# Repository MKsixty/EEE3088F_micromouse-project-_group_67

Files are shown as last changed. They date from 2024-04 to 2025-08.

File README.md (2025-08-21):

# EEE3088F_micromouse-project-_group_67

Overview

This repository contains the design files, documentation, and testing results for the sensor subsystem of a Micromouse robot, developed as part of the EEE3088F course at the University of Cape Town. The sensor board is designed as a custom PCB inspired by the UCLA Micromouse project but tailored through specific design decisions to meet project requirements and ensure optimal performance. Its primary role is to provide reliable wall detection on the front, left, and right sides of the Micromouse to enable autonomous maze navigation.

Design Summary

Emitters & Detectors: Uses IR333C infrared LEDs and TEFT4300 phototransistors, chosen for their closely matched wavelength (≈940 nm) for fast response and accurate detection.

Emitter Circuit: Powered by the 3.7 V LiPo battery, with 47 Ω current-limiting resistors ensuring ~70 mA drive for strong radiant intensity. 4.7 μF bypass capacitors filter noise on the LED supply.

Switching: Implemented with MMBF170 N-channel MOSFETs driven by STM32L476 PWM GPIOs. Gate resistors (100 Ω) and pulldowns (47 kΩ) ensure safe and stable operation.

Receiver Circuit: Uses a voltage divider (470 Ω & 1.5 kΩ) to keep outputs <3.3 V for STM32 ADC compatibility. A unity-gain buffer with LM324 op-amp protects ADC inputs from noise and spikes.

Form Factor: PCB dimensions ≤70 mm × 30 mm, cost-effective, and compatible with standard JLCPCB manufacturing limits.

Failure Management: Includes test points, through-hole components for easy rework, and jumper options to adjust resistor networks if needed.

Features

Accurate wall detection at up to 15 cm.

PWM-controlled IR switching for power efficiency.

Designed for direct integration with the STM32L476 processor board via a 14×2 pin header.

Supports three independent sensor channels (front, left, right).

Repository Contents

PCB design files and schematics.

Component datasheets (IR333C, TEFT4300, LM324, MOSFETs).

Integration code for STM32L476 (sensor readout and PWM control).

Project report, test logs, and acceptance test procedures.

Testing

The board underwent short-circuit checks, current consumption tests, PWM switching validation, and functional wall-detection tests. Issues such as LED orientation errors and interference between sensors were identified and mitigated using jumper reconfiguration and potential PWM timing adjustments in firmware.

Future Improvements

Implement time-multiplexed PWM driving to reduce crosstalk between sensors.

Optimize current draw to meet <100 mA power efficiency target.

Explore improved ADC filtering for cleaner sensor output.

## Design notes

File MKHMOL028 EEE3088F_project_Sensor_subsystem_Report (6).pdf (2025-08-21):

# Interim Design Report

Micromouse sensor Subsystem


Prepared by:
Molise Mokhakala

Prepared for:
EEE3088F
Department of Electrical Engineering University of Cape Town

May 17, 2024

# Declaration

1. I know that plagiarism is wrong. Plagiarism is to use another’s work and pretend that it is one’s own.
2. I have used the IEEE convention for citation and referencing. Each contribution to, and quotation in, this report from the work(s) of other people has been attributed, and has been cited and

referenced.

3. This report is my own work.
4. I have not allowed, and will not allow, anyone to copy my work with the intention of passing it off as their own work or part thereof.

May 17, 2024

Name Surname | Date

ii

# Contents

1 Introduction | 1
2 Requirements Analysis | 2
3 Subsystem Design | 4
4 Acceptance Testing | 9

iii

# Chapter 1

# Introduction

## 1.1 Problem Description

The aim of this project is to design and manufacture a sensor module for a micromouse. A micromouse is a small robot that can autonomously move through a maze to get to the centre.The sensor subsystem plays a crucial role of being the micromouse’s eyes in order to accomplish the aforementioned. As

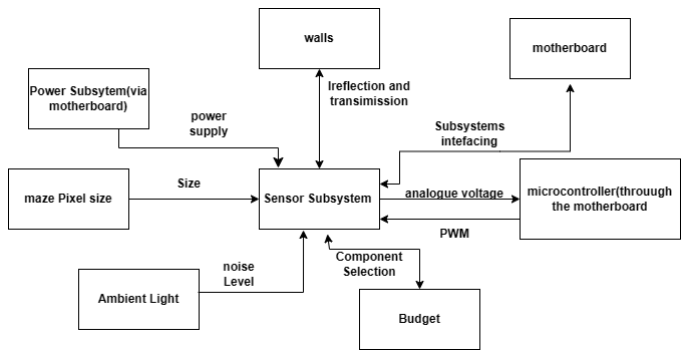
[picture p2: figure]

Figure 1.1: Context diagram for the sensor subsystem in the whole project

illustrated in the above figure, the sensor subsystem primarily detects obstacles in the environment of the micro-mouse specifically walls in front and on the side of the micromouse using transmission and reflection. Subsequently this allows the mouse to identify and avoid collisions with walls, adjusting its path accordingly to successfully reach the center. The microprocessor using its ADC examines analogue voltage outputs from the sensor to determine the presence of the wall.

## 1.2 Scope and Limitations

The project’s focus is to design PCB boards for the sensor submodule and write code necessary for integration of the PCB with the microprocessor boards. The PCB must primarily offer effective and accurate wall detection in front and on the micro-mouse’s right and left sides. The subsystem is to be designed to utilise switching techniques that enabling to have efficient battery use. Furthermore, testing procedures concentrate on the functionality of the sensor subsystem within the given requirements. However, this subsystem does not include the design or manufacture of the processor board and power subsystem . Testing is not conducted of the power subsystems and other subsystems. The manufacture of the two PCBs is limited to a maximum of $30. Additional restriction include no prototyping due to

limited time before demonstration.

## 1.3 GitHub Link

repo link (contains datasheets and project versions references in the document) (https://github.com/MKsixty/EEE3088F_micromouse-project-_group_67)

# Chapter 2

# Requirements Analysis

## 2.1 Requirements

The requirements for a micromouse power module are described in Table 2.1.

Table 2.1: User and functional requirements of the Sensor subsystem.

Requirement ID | Description
UR01 | It should have a switching mechanism
FR01 | It must detect walls in front and on the side of the micromouse
UR02 | It must be of the appropriate geometry for the maze pixels
UR03 | It must be cost-effective. Two PCBs cost at most $30
UR04 | Its pin headers must connect to the motherboard at the right configuration for STM32L476
UR05 | It should use only components available on JLCPCB excluding the pin headers
FR02 | the sensor output must be analogue
FR03 | It should reduce ambient light effects
FR04 | It should be power efficient and not drain the battery before completing the maze.
FR05 | should be capable of using LiPo 800mAh 3.7V power supply
FR06 | have written code that allows sensing board to detect walls in front, to the left and to the right of the micromouse.

## 2.2 Specifications

The specifications, refined from the requirements in Table 2.1, for the micromouse sensor module are described in Table 2.2.

Table 2.2: Specifications of the sensing subsystem derived from the requirements in Table 2.1.

Specification ID | Requirements ID | Description
SP01 | UR01 | IR LED switches on when microcontroller GPIO pins’PWM reaches 3.3V and is off below 2.5V
SP02 | FR01 | should have 3 sensors per PCB (one at the front and two on the sides) with detection range of 15cm
SP03 | FR01 | use 900-950nm Infrared LED and detector
SP04 | FR02 | the sensor output is analogue voltage in the range 0V to 2.8V
SP05 | FR03 | Photo-detector has daylight blocking filter with bandwidth matched with 900-950nm IR emitters
SP06 | FR04 | only 100mA when all 3 sensors are operational
SP07 | FR05 | the IR emitter and detector should work on the LiPo 800mAh 3.7V
SP08 | UR02 | must have maximum width of 30mm and length of 70mm
SP09 | UR03 | have a maximum of 4 low cost JLCPCB extended components
| UR05 | and the rest should be basic
SP10 | UR04 | 14x2 odd even standard pinheaders should be on sensor board
| | and matches the processor board connections thus the testing booad
SP11 | FR06 | Code must be compatible with the 2nd year STM32F0 devkit and toggle PB7 for left, PB6 For front and PB5 for right

## 2.3 Testing Procedures

A summary of the testing procedures detailed in chapter 4 is given in Table 2.3.

2.4. Traceability Analysis

Table 2.3: acceptance tests summary

Acceptance Test ID | Description
AT01 | short circuit test
AT02 | check if N mosfet low side switching works
AT03 | check if IR LEDs work
AT04 | check current consumption
AT05 | check if PWM switching mechanism works
AT06 | check if receiver circuit works
AT07 | check if walls can be detected
AT08 | check code used for integration works
AT09 | check if 14x2 pin headers can fit into the slots on processor board
AT09 | confirm board size

## 2.4 Traceability Analysis

The show how the requirements, specifications and testing procedures all link, Table 2.4 is provided.

Table 2.4: Requirements Traceability Matrix

# | Requirements | Specifications | Acceptance Test

1 2 3 4 5 6 7 9 10 | UR01 FR01 FR02 FR03 FR04 FR05 UR02 FR06 UR04 | SP01 SP02, SP03 SP04 SP05 SP06 SP07 SP08 SP11 SP10 | AT05,AT02 AT04,AT07,AT08 AT07 AT06 AT04 AT01 AT10 AT07 AT09

### 2.4.1 Traceability Analysis 1

UR01 is this from which SP01, use of PWM as swicthing means, can be derived. This is because the provided microcontroller offer PWM. To test this AT05 and AT02 are suggested because these test whether the mosfet used does switch or not.

From FR01, SP02 and SP03 can be derived because for the sensor subsystem to be functional in the task of sensing the walls on the side and front, all three sensor must use IR transmission and reflection to detect obstacle. These can be tested through AT07,AT08 and AT04 which tests if the emitter and transmitter are functional .This is because this tests require all three of the sensors to be operational

From FR02 , sP02 is derived because inorder for the sensor to have output that is analogue and can be used by the microcontroller ADC it is limited to 0-2.8V. Subsequently this means test AT07 confirms whether the voltage registered when an obstacle is present indeed falls with the 0-2.8V limit.

# Chapter 3

# Subsystem Design

## 3.1 Design Decisions

The detection of the wall, requires a wave that can be transmitted by the sensor subsystem and reflected by the wall back to the subsystem. Although there are various waves that can be used such as sound, this design will use Infrared as it is faster than sound moving at the speed of light. Thus this would give the micromouse a fast response. The 3.1 gives comparisons made between the most feasible emitters for the sensor subsystem.

Table 3.1: IR emitter component selection

| forward current(typ) | forward current | Power Dissipation | Spectral range Sensitivity | Peak Wavelength | half angle(Deg) | Cost
TSAL6100 | 1.35V | 100mA | 160mW | 910-970nm | 940nm | 10 | $0.2147
IR333C | 1.2V | 20mA | 150mW | 895-995nm | 940nm | 20 | $0.0339
SFH4556 | 1.5V | 100mA | 150mW | 820-860nm | 840nm | 20 | $0.6120

Table 3.2: IR emitter component selection pros against cons comparison

| TSAL6100 | SFH4556 | IR333C
pros | least expensive, meeting the UR03 requirement | 20 degrees half angle making it large enough for side wall detection(FR01) especially if the emitter needs to be placed at an angle on the PCB. | low current requirement for peak wavelength of 940nm, meeting SP05 Half angle same as SFH4556 making it also suitable for FR01 lowest voltage drop at peak walength current of 1.2V
cons | small wavelength spectral range make it less suitable for spectral range less than 900nm which could be generated if there slight changes current values | most expensive thus less likely if UR03 is to be met high current requirement of 100mA for peak wavelength the highest voltage drop of 1.5 V | lower maximum power dissipation of 150 compared to the other two.

IR333C is selected given its advantages over the other components and although it has one the lower maximum power dissipation values,given it will not be driven to close to the max dissipation value it should be fine.

The use of pulse width modulation(PWM) requires the use of components that can switch on and off

depending on whether the supply is high or low . Transistor are useful in this regard. Subsequently for low side switching which is easy to implement, a comparison between the NPN BJT ZTX652 and N channel mosfet MMBF170 on their effectiveness in this configuration is made .

MMBF170 provides faster and more stable switching at a lower cost than ZTX652. Although more difficult to hand solder than ZTX652, it can still be hand soldered meaning this does not negate the

3.1. Design Decisions

Table 3.3: SWitching component selection pros against cons comparison

| MMBF170(N-channel Mosfet) | ZTX652(NPN BJT)
pro | Idmax =0.5A meaning it can carry the 20mA required by IR333C low voltage requirement of 0.13V at 250mA which means it can dissipate less power It is an SMD thus is small can save space on the PCB subsequently helping in achieving UR02. faster switching time as shown in table for both the switching on and off thus making it more suitaable for SP06 and SP05 As a mosfet it has a high current gain making more stable for changing drain currents and more stable than the ZTX652 | is THT thus is easier to solder by hand if revision are needed Typically needs atleast +0.9V at the base thus can work at the 3.3V of the microcontroller. Thus making it more suitable for achieving SP06 and SP05.
cons | It is small making it hard to solder by hand if revisions are needed Needs more voltage to be active which is greater or equal to Vgs threshold of 1.6V | since it is a BJT, it is slightly more affected by temperatures making it less stable in switching costs more thus making it difficult to achieve UR03

MMBF170 use in the circuit. Thus MMBF170 was selected for this design.

Given the selection of the IR333C, the following receivers are selected as feasible components as they are sensitive to IR333C’s peak wavelength of 940nm.

Table 3.4: IR receiver component selection

| forward voltage | daylight blocking | wavelength of max sensitivity | spectral range | half angle | unit cost
BPV10NF | VR=0.85V at IR=50mA | present 850-950nm | 940 | 780-1050 | 20 | $0.4035 (extended)
TEFT4300 | VCE sat = 0.3 | Present 900-950nm | 925nm | 875-1000nm | 30 | $0.2147 (extended)

Table 3.5: IR receiver component pros and cons

| BPV10NF | TEFT4300
Pro | has a larger daylight-blocking filtering in the range 780-1050nm hence can filter more of the ambient light compared to TEFT4300.Thus making it very useful in achieving SP03 has a peak detection wavelength of 940nm which exactly matches IR333C’s thus can operate at optimum detection level | has a daylight blocking filter range 875-1000nm so can still be used to meet SP03. has a larger half angle of 30 degrees thus can be useful for detection at angles. Thus becomes very useful for FR01. costs less at $0.2147
cons | more expensive at $0.4035 | has a lower peak wavelength detection of 925nm compared to the transmitted one of IR333C of 940nm

TEFT4300 is selected over BPV10NF because it costs less subsequently is effective in achieving UR03 and SP10. Even though it has a lower peak wavelength of 925nm while BPV10NF has a peak wavelength of 940nm which is exactly 940nm, the larger half angle is another reason it was choosen. This is because IR333C gives off a range of wavelengths 895-995nm thus 925nm is also radiated. Subsequently this means the wavelength disadvantage is overlooked and TEFT4300 was selected.

3.1. Design Decisions

### 3.1.1 Final Design

The following design are inspired by ucla micromouse design (https://projects.ieeebruins.com/micromouse/) however meticulous design decisions were made to the project’s requirements and to ensure optimal performance and functionality. The IR333C and TEFT4300 are selected for their matching wavelength ranges, which enables fast response time. Given that as microcontroller STM32L476’s GPIOs give out low currents, the IR333C emitter circuitand The receiver circuits are also supplied by the 3.7 V battery from the power subsystem. 47 ohm resistor is choosen to limit the current through the IR333C whilst ensuring it has current of 70mA which results in IR333C large radiant intensity. The 4.7 uF bypass capacitors across the LEDs ensures a clear signals when supplied by DC.

The 47k resistor connected to ground is placed at the gate of N channel mosfet to ensure the gate is zero when there is no voltage supplied. The gate of the MMBF170s is connected to the GPIO PE of the microcontroller for PWM since for the N channel mosfets current is not a requirement to switch on. MMBF170’s gate to source threshold voltage is 1.6V thus 3.3V of the pins will switch the mosfets on. 100 ohm resistors at each of the MMBF170’s gate is used for current limiting.
The unity voltage buffer is used in the circuit to protect the ADC from sudden spikes in voltage as a result of noise. The IC LM324 is then used because it reduces the space used thus achieving UR03. Voltage divider in the receiver circuit consisting of 470 and 1.5 k ohm resistors to ensure that the output is less than 3.3V of the inbuilt ADC of STM32L476.
A detail schematic with the above decisions is shown below.

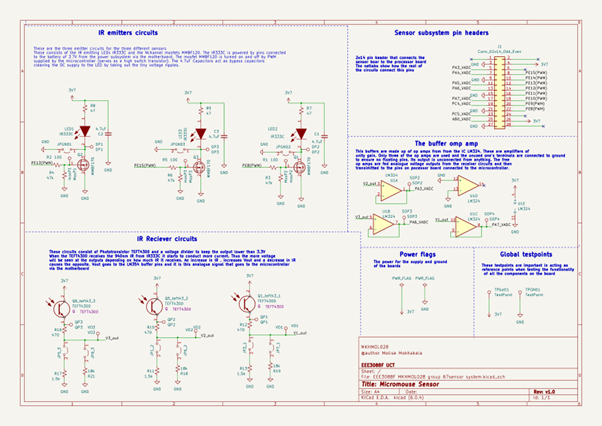
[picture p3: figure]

Figure 3.1: Schematic

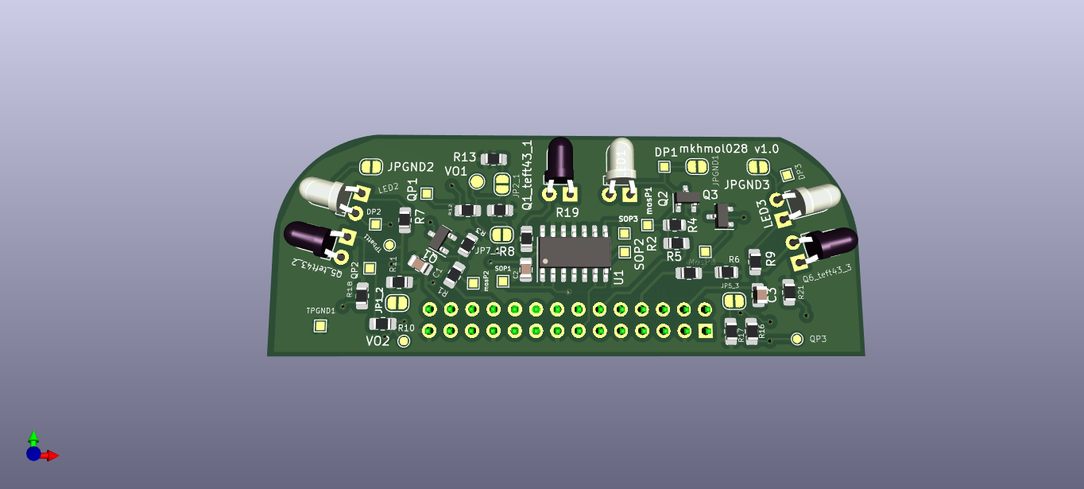
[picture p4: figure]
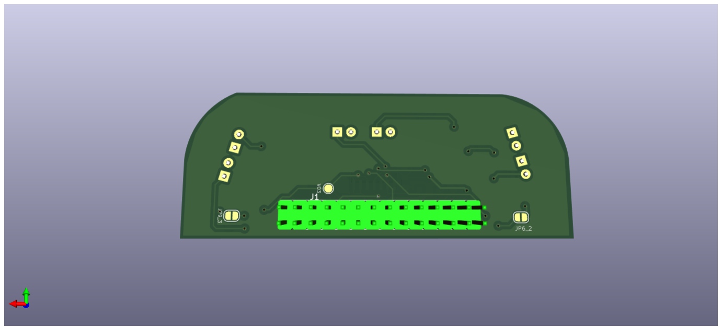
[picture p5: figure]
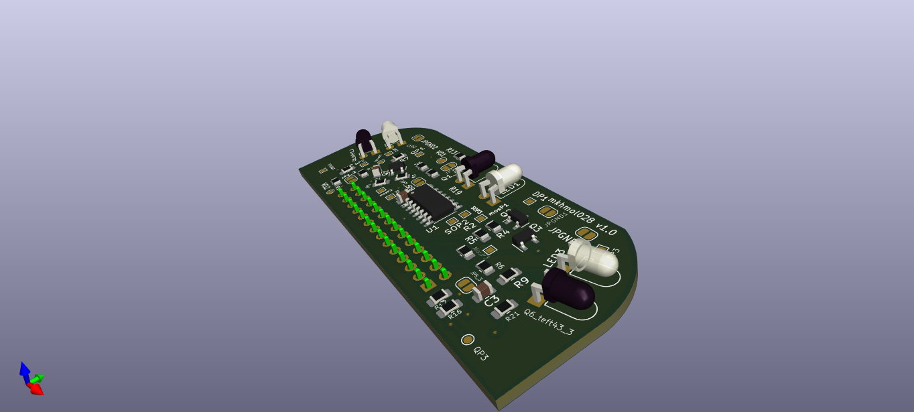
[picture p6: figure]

(a) Front PCB | (b) Back PCB | (c) 3D PCB

Figure 3.2: PCB

3.2. Failure Management

## 3.2 Failure Management

Table 3.6: failure Precautions used in the PCB

Name | Description
Test Points | Varies test points are placed all over the board across vital components to dectect specific component failures. The testpoints are named according the components they are to be used in testing for. Example DP3 is the test point for the IR333C giving out V3out in the Schematic The voltage across the components can be determined using the global tespoints TPbatt(battery testpoint)and TPGND1(ground testpoint). as references.

Though-hole emitters(IR333C) and receivers(TEFT4300)

open Jumpers | The open jumpers connect various branches of circuits . Soldering them closes the circuit and desoldering opens it .The jumpers JP5_3 and JP9_3 connect to the two branches with 1.5k ohms and 18k ohms resistors respectively. If 1.5k ohms does not give the required 2.8V, the bigger resistor of 18k can be used for a larger voltage output. The jumpers are named after the sensor they are responsible for using (_number). JPGND1, JPGND2 and JPGND3 connect their respective emitters to 3.7V incase the switching machinism fails.

Through holes are easy to desolder if polarity does not match the one specified in the PCB design
due to some manufacture error. If in the wrong orientation ,the commonents can be resoldered in the right direction. in case replacement is necessay.

## 3.3 System Integration and Interfacing

To integrate the subsystem with the rest of the systems ....

Table 3.7: Interfacing specifications

Interface | Description | Pins/Output
1001 | PWM from microcontroller for switching the sensor transmitter circuits on and off | PWM:Sensorboard Pin 12 to motherboard pin 26 to STM32L476 PE13(GPIO) PWM: Pin 8 sensor board to pin 24 motherboard to STM32L476 PE15(GPIO) PWM: Sensorboard Pin 22 to Motherboard pin 32 to STM32L476 PE8(GPIO)
1002 | analogue voltage output to STM32L476’s inbuilt ADC | Pin 5 of sensor board to Pin 43 of motherboard to STM32L476 PA3 Sensorboard Pin 13 to Motherboard Pin 40 to STM32L476 PA6 Sensorboard Pin 17 to Motherboard Pin 38 to STM32L476 PA7
1003 | battery voltage supply from power subsystem via the motherboard to the sensor subsystem. | Power: Pin7 of Power Subsystem to Pin 4 of Sensor subsystem(0-3.7V) Power: Pin 26 of Power Subsystem to pin 8 of Sensor Subsystem(0-3.7) GND: Pin 27 and Pin 15 of sensor subsystem to Pin 49 and 75 of motherboard to pin5 and 6 of power subsystem

below is the interfacing diagram and table describing the interacting of the Sensor subsystem with other subsystems. These ignore unused pins by the sensor module.

3.3. System Integration and Interfacing

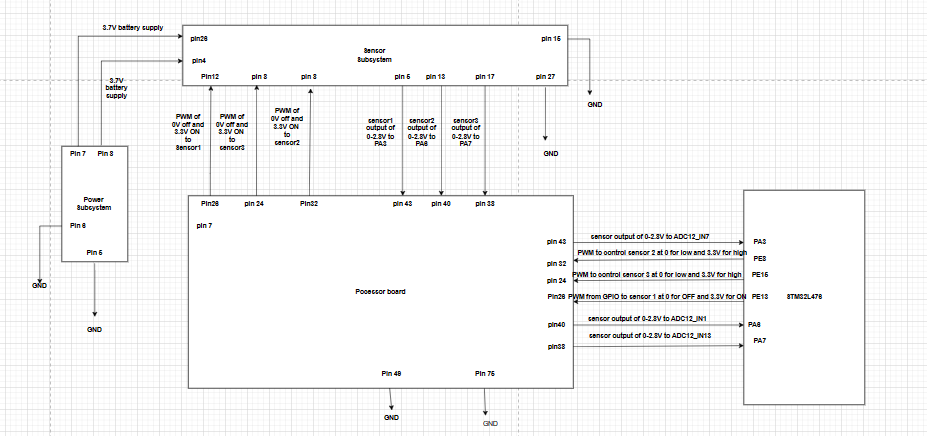
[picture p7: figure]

Figure 3.3: Interface diagram showing the interactions between all the subsystems in the context of the Sensor subsystem

# Chapter 4

# Acceptance Testing

## 4.1 Tests

Table 4.1: Subsystem acceptance tests

Test ID | Description | Testing Procedure | Pass / Fail Criteria

AT01

AT02

AT03

AT04

AT05

AT06

AT07

AT08

AT09

short circuit test. This is conducted to make sure that 3.7V supply supplied at

pin 4 and pin 26
is not ground . Subsequently ensuring all the circuit SP08 is achieved

Set the lab desk multimeter to continuity test mode. Connect probes to the multimeter. Inserting
a black test leads to COM and a red probe to the V jack . Place the black lead on
the ground test point on the board(TPGND1) and place the red test lead on pin 26 and then pin 4 of the pin header. Listen for a beep from the multimeter when probe is at each pin

pass: No beep from multimeter when not on ground

Fail:beep

Check if the Nchannel mosfet works to confirm

to confirm if the sensors works when supplied by the 3.3V of the microcontroller GPIO.

Connect pins 4, and 26 of the pin header to a 3.7V lab DC supply and the supply’s ground
to pin 27 and 15 using some male-to-female jumper wires Connect the females to the pins of the pinheader and their corresponding males to the supply

accordingly. Connect positive rail of the other DC supply set to 3.3V to pin 12,26 and 8 , connect the grounds

together.
Set the multimeter to DC voltage mode With the probes still connected to the multimeter as in AT01. Place the red probe on DP1 and the

black probe on TPGND1. Read the voltage drop across the screen of the multimeter

pass: Voltage greater than 0V

Fail: Voltage reading= 0V

Check if IR LEDs works
using the multimeter polarity test. This
is done to check if the IR333Cs are connected in the configuration subsequently whether they are on

Set the lab desk multimeter to diode polarity test mode . The connection of the leads
to the multimeter is still unchanged. Connect the red test lead(positve lead ) to the side of the LED that is supposed to be the anode based on the schematic. And the COM
lead on the other side. Look at the screen of the multimeter for voltage readings

pass: multimeter Voltage is greater or equal to 1V

fail: multimeter voltage reading = OV

check the current consumption . Check if the expected current is drawn by the emitter circuit Subsequently this helps to check whether whether the all three circuits work. As it is expected

that the three sensors will draw approximately 150mA when operational on 3.3 DC

Connect the females to the pins of the pinheader and their corresponding males to the supply

monitor the current on the screen of the power supply

pass: current drawn =150mA +/-20mA

fail : current drawn <130mA or current drawn >170mA

Check if PWM switching mechanism
works. This is to confirm that when the pin 22 , pin 12 and 8 are supplied with 3.3V square wave with 50% duty cycle , the IR333Cs are still on. Thus works on low current

Connect the pin 4, 26 to 3.7V DC supply and the grounds to pin 27 and 15 using the male to female jumper wires as in AT02. Using a wave generator , set the wave to square wave of 3.3v and frequency 1 kHz . Connect the pin 12, 26 and 8 to the positive terminal of the wave generator and the ground to the other the grounds.
Look at the supply current on the screen of the DC power supply

pass: supply current <100mA

fail: supply current >100mA

Check if receiver circuit works . This is to confirm
that the output of the sensors does change depending on the amount of IR with the condition the IR333Cs have been confirmed to be working ,

Connect the pin 4, 26 to 3.7 V DC supply and the ground to pin 27 and 15 using the aforementioned male to female jumpers. Connect the 3.3 V DC supply to pin 12, 26 and 8 and connect its ground to the

other grounds. Use the multimeter leads in the same set up as AT02, place the COM lead to TPGND1 and the other lead on V01 (sensor 1 receiver output). Note the voltage as V1.

Place a cardboard piece at 5 cm in the front of sensor 1 and note the multimeter voltage reading as V2. Do the same test for the other

pass: V2-V1>0.1

Fail: V2-V1= 0 or V2-V1<0.1

Check if walls can be detected. Check if the mazes walls can be detected from the center of the test maze

pixel

Connect the pin 4, 26 to 3.7 V DC supply and the ground to pin 27 and 15 using the aforementioned male to female jumpers. Connect the 3.3 V DC supply to pin 12, 26 and 8 and connect its ground to the

other grounds. Use an oscilloscope to measure the DC voltage output. Place the ground of the probe at TPGND1 and the probe tip on S0P4 (sensor 1 receiver output). Note the voltage as V1.

Place the front wall and note the oscilloscope voltage
reading as V2. Do the same test for the other

Pass: Sensor 1 voltage >=1.5V sensor 2 and 3 >= 1

fail: Sensor 1 voltage <1.5 Sensor 2 and 3 voltage <1

Check if PB7, PB6 and PB5 on STM32FO devkit turn on based on the walls present. This test confirms that the code works and the sensor can be integrated with the STM32L476

Place the sensor board at the centre of the test maze pixel Connect the pin 4, 26 to 3.7 V DC supply and the ground to pin 27 and 15 using the aforementioned male to female jumpers. Connect the 3.3 V DC supply to pins 12, 26 and 8 and connect its ground to the

other grounds.
connect pin17(PA7) of the sensor board to PA1 of devkit.
pin5 to PA0 of Devkit and pin 13 to PA2 of devkit.Place the front and look at the LEDS on the devkit Do the same test for the other walls

Pass: PB7 on when left wall present PB6 on when front wall present PB5 on when right wall present

Fail: PB7, PB6 and PB5 on when corresponding walls are not present

14x2 pin headers have the needed configuration as the pins. This ensures that the sensor board can be integrated on

the testing rig and motherboard

Fit the pins on to the processor board slot pass: all pins fit into the slots places

fail: at least one pin does not fit slot configurations

AT010 | measure board size.
this is done to confirm that the size of the board is as needed for SP08 | use 10cm rule to measure the width and length

pass: length<=70mm and width<=30mm fail: length>70mm or width>30mm configurations

4.2. Critical Analysis of Testing

Table 4.2: Subsystem acceptance test results

Test
ID | Description | Result
AT03 | check if IR LEDs work | failed
AT04 | check current consump-
| tion | passed
AT05 | check if PWM switching
| mechanism works | passed
AT06 | check if receiver circuit
| works | passed
AT07 | check if walls can be de-
| tected | failed
AT08 | check code used for inte-
| gration works | failed

AT09

check if 14x2 pin headers
can fit into the slots on
the processor board

passed

AT09 | confirm board size | passed
AT02 | check if N MOSFET low
| side switching works | passed
AT01 | short circuit test | pass

## 4.2 Critical Analysis of Testing

### 4.2.1 AT03

The left LED was oriented in the wrong direction thus when the expected anode was connect the V testing lead of the multimeter and the COM testing lead connected to the expected cathode 0V was registered on the display. And the reverse orientation resulted in a voltage drop of 1.2V was registered. Subsequently this meant the LED was placed the other way round. The fact that the though-hole IR333C was used became very useful, as this meant the LED could be easily desoldered. This was done and the LED leads were careful bend the other way round. And the LED was set right back into the holes and solder with the correct orientation. This could have happen because some of the silk mask for the LED was cut due to placing the LED right at the edge and this could have resulted in this manufacture error.To prevent this , it should also be made explicit on the manufacture BOM that specific components are in this orientation. Again silk masks should be used effectively as indication of the component orientation to prevent manufacture misplacement

### 4.2.2 AT04

The result was a pass because the current that was registered on the power supply was 150mA. By supply the gates of N channel with a known 3.3V DC supply which is larger than the gate to source threshold voltage of 1.6V, this ensures that MMBF170 is on. The test required the current to be non zero and above 130 mA as expected if all three sensors are operational.Given that 150 mA this means its very likely that all the sensors are operational. This result further suggests that the IR333Cs and TEFT4300 are soldered in the right orientation. This current drawn says that approximately each sensor draws 50mA in its operation. Subsequently, the power dissipated by each sensor is 0.050A*3.7V

= 0.185 W and the total dissipated power by all three sensors is then 0.555W. This is high because the

4.2. Critical Analysis of Testing

sensor consumes more than the 100mA specified in SP06. Subsequently this means the sensor should operated using PWM.As this could lower the consumed current.

### 4.2.3 AT05

This worked because the supply current registered was 69.6mA, This is certainly lower than the 100mA threshold set in the test and the 150mA in AT05. Given that the above test already establish that emitter circuits are operational, this means that the all three sensor are now operating at a lower power.

### 4.2.4 AT07

This was a fail because the front sensor could not have an output greater than 1.5V.This is because the receiver voltage divider was only made up of 470 ohm resistor and 1.5k resistor. This meant that if the current is low , the voltage drop across 1.5k resistor would be low. To correct this JP2_1 was desolder and JP7_1 was soldered instead this created the voltage divider with 470(R12) and 18k(R19).

The sensor’s output increased 2.3V when wall is present. Thus the jumper failure management became very useful in this regard. To make sure that there are even more options of resistors , resistors could be populated on the board even if they are not in use so that they can be desoldered and placed at a required place if the resistance is not enough

### 4.2.5 AT08

It is a failed because when either the left or right walls is removed with the other two walls present , all three LEDs are on , subsequently the sensor without wall registers wall. This due to putting the sensors at angles which means that the the reflections from the two walls still reach the sensor. Also the code did not implement PWM which could have been used to turn on the emitters at different times to prevent interference. Delays in the code of PWM at each pin can be chosen meticulously to allowed some time between the different sensor detections.

4.2. Critical Analysis of Testing

bibliography

UCLA, “Micromouse | IEEE at UCLA Project Docs,” projects.ieeebruins.com, 2024. https://projects.ieeebruins.com
/micromouse/ (accessed Mar. 17, 2024).

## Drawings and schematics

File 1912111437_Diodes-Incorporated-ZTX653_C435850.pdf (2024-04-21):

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

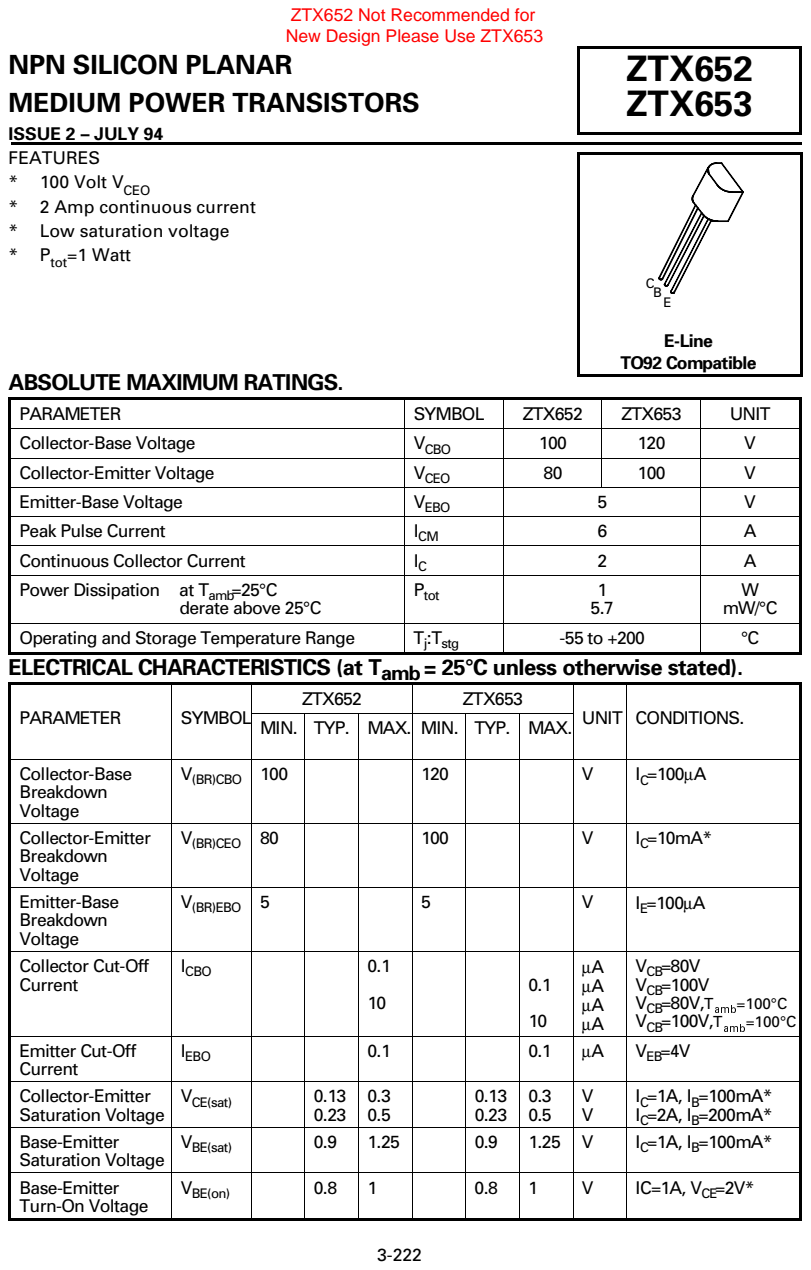
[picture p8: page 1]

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

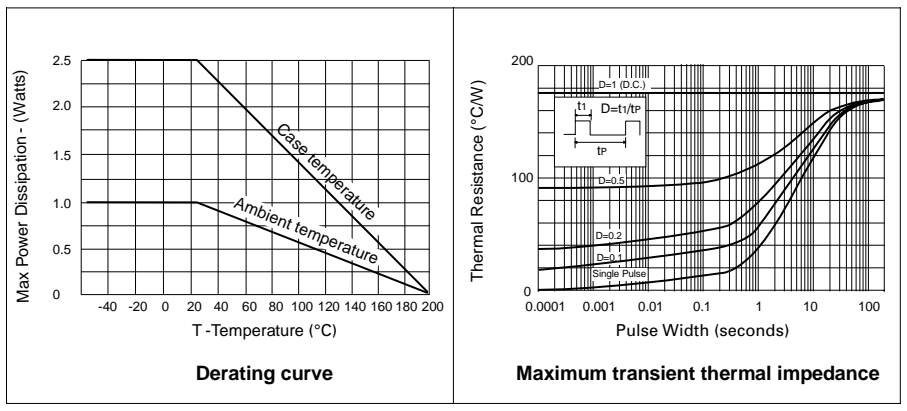
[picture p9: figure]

# ZTX652 ZTX653

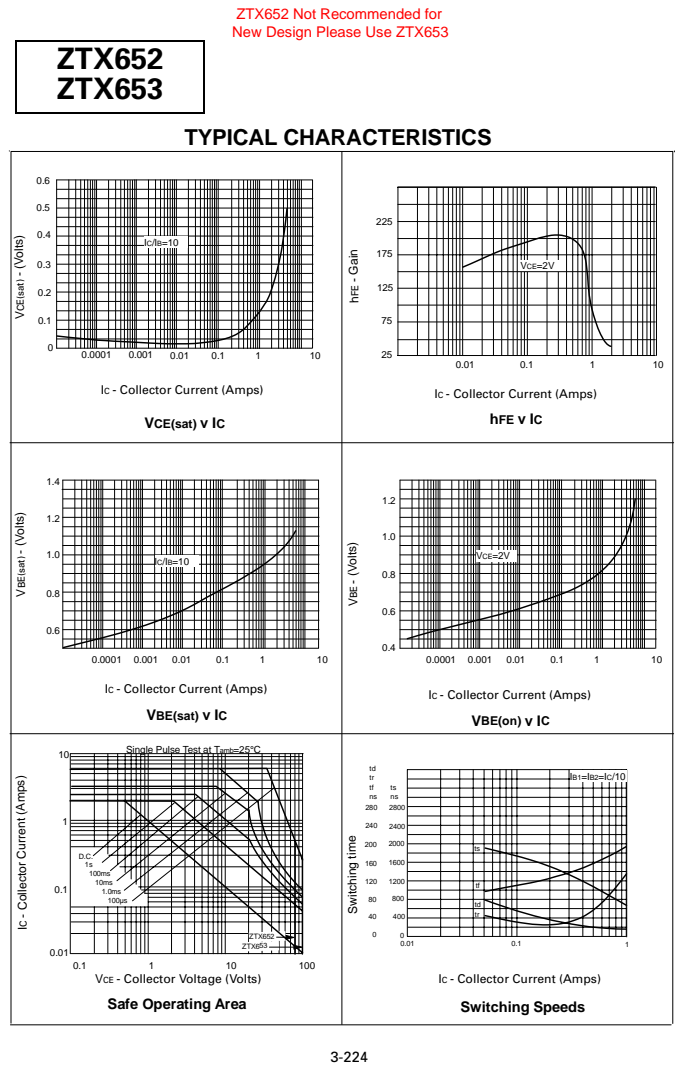
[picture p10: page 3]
TYPICAL CHARACTERISTICS; VCE; t) - (Volts); Single Pulse Test at Tamb=25°C; VBE; sat) - (Volts); hFE v IC; hFE; - Gain; VCE=2V; Volts; Switching time; ZTX652; ZTX653

ZTX652 Not Recommended for
New Design Please Use ZTX653

IC - Collector Current (Amps)

VCE(sat) v IC

VCE=2V

VBE(sat) v IC

VBE(on) v IC

C - Collector Current (Amps)

td
tr

VCE - Collector Voltage (Volts)
Safe Operating Area

Switching Speeds
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

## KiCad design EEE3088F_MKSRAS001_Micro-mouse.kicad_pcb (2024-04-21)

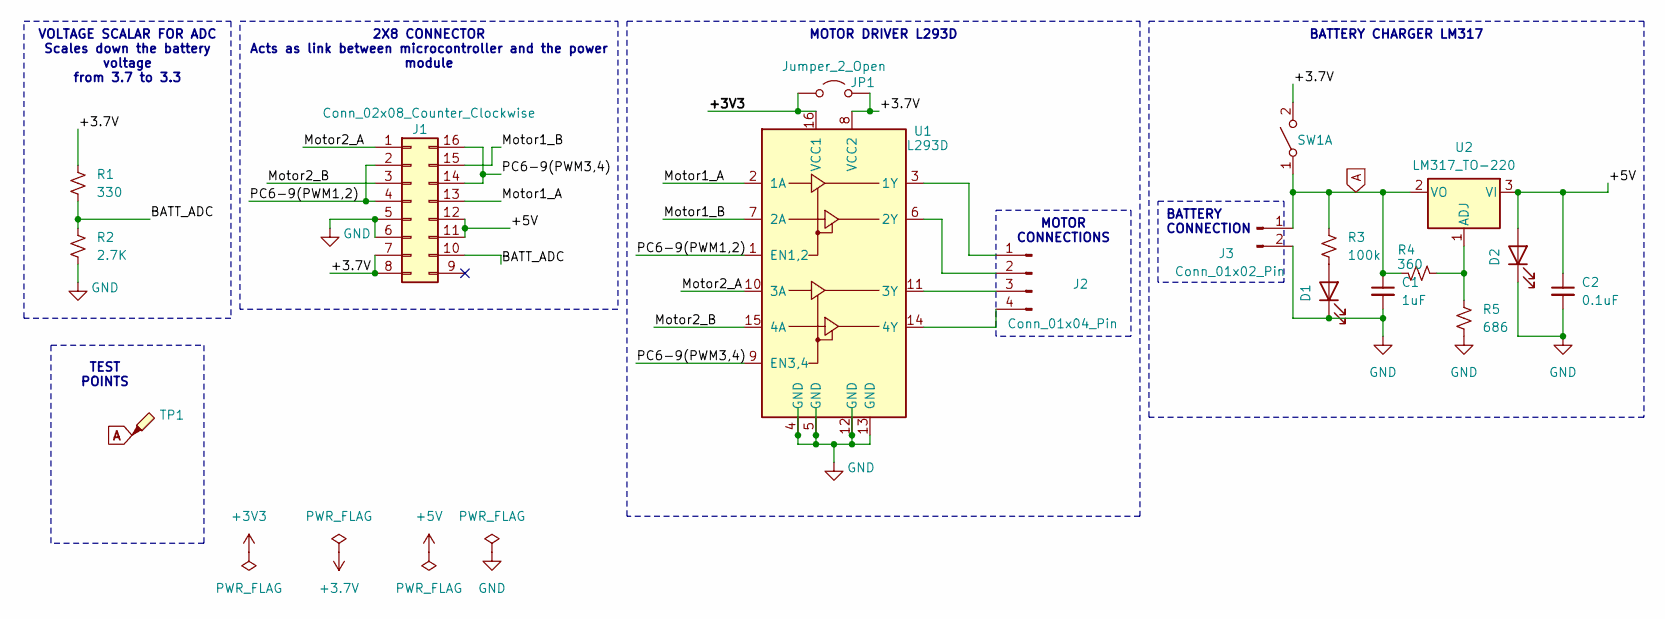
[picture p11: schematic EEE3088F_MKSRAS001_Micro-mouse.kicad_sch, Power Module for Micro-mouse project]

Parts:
C1: 1uF; C_0201_0603Metric
C2: 0.1uF; C_0201_0603Metric
D1, D2: LED; LED_0201_0603Metric
J1: Conn_02x08_Counter_Clockwise; JST_PUD_B16B-PUDSS_2x08_P2.00mm_Vertical
J2: Conn_01x04_Pin; PinHeader_1x04_P1.00mm_Vertical
J3: Conn_01x02_Pin; JST_PH_B2B-PH-K_1x02_P2.00mm_Vertical
JP1: Jumper_2_Open; KEYSTONE_5110
R1: 330; R_0201_0603Metric
R2: 2.7K; R_0201_0603Metric
R3: 100k; R_0201_0603Metric
R4: 360; R_0201_0603Metric
R5: 686; R_0201_0603Metric
SW1: SW_DPST_x2; SW_DIP_SPSTx01_Slide_Omron_A6S-110x_W8.9mm_P2.54mm
TP1: TestPoint_Probe; Pin_D1.0mm_L10.0mm
U1: L293D; DIP-16_W7.62mm
U2: LM317_TO-220; TO-220-3_Vertical

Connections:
+3.7V: J1.7, J1.8, JP1.2 (B), R1.1, SW1.2 (B), U1.8 (VCC2)
+3V3: JP1.1 (A), U1.16 (VCC1)
+5V: C2.1, D2.2 (A), J1.11, J1.12, U2.3 (VI)
/BATT_ADC: J1.10, R1.2, R2.1
/Motor1_A: J1.13, U1.2 (1A)
/Motor1_B: J1.15, U1.7 (2A)
/Motor2_A: J1.1, U1.10 (3A)
/Motor2_B: J1.3, U1.15 (4A)
/PC6-9(PWM1,2): J1.2, J1.4, U1.1 (EN1,2)
/PC6-9(PWM3,4): J1.14, J1.16, U1.9 (EN3,4)
A: C1.1, J3.1, R3.1, R4.2, SW1.1 (A), TP1.1, U2.2 (VO)
GND: C1.2, C2.2, D1.1 (K), D2.1 (K), J1.5, J1.6, J3.2, R2.2, R5.2, U1.4 (GND), U1.5 (GND), U1.12 (GND), U1.13 (GND)
unnamed: D1.2 (A), R3.2
unnamed: J2.1, U1.3 (1Y)
unnamed: J2.2, U1.6 (2Y)
unnamed: J2.3, U1.11 (3Y)
unnamed: J2.4, U1.14 (4Y)
unnamed: R4.1, R5.1, U2.1 (ADJ)

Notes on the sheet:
2X8 CONNECTOR Acts as link between microcontroller and the power module
BATTERY CHARGER LM317
MOTOR DRIVER L293D
BATTERY CONNECTION
TEST POINTS
MOTOR CONNECTIONS
VOLTAGE SCALAR FOR ADC Scales down the battery voltage from 3.7 to 3.3

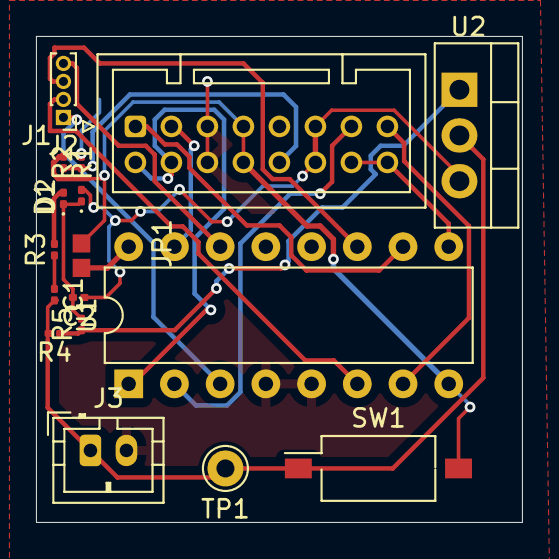
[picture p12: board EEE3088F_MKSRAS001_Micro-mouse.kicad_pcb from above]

Board: 2 copper layers, 27.0 x 27.0 mm, 17 parts (0 on the bottom side), 18 nets.

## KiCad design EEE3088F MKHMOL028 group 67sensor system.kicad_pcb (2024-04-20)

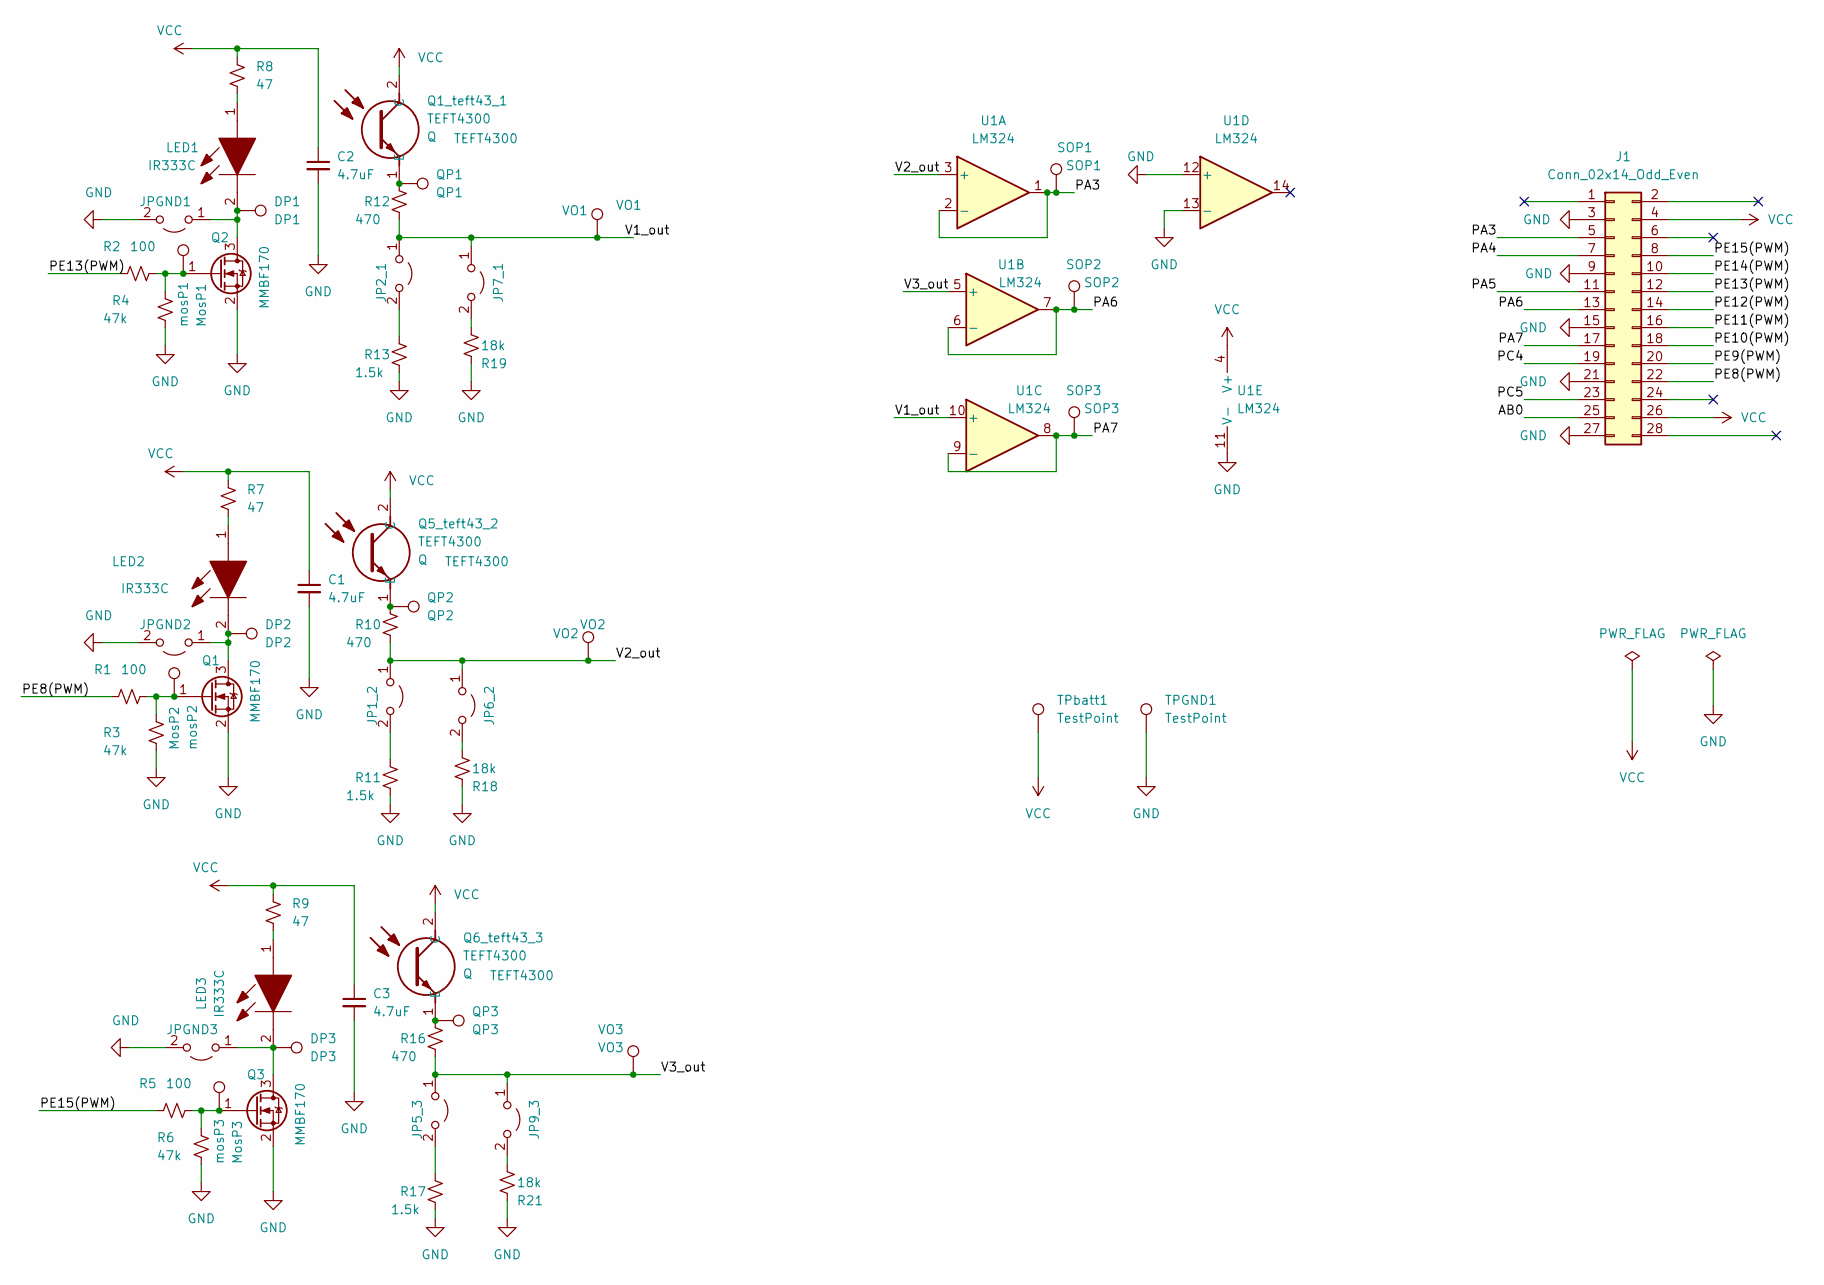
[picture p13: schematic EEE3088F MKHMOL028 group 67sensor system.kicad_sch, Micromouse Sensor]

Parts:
C1, C2, C3: 4.7uF; C_0805_2012Metric
DP1: DP1; TestPoint_Pad_1.0x1.0mm
DP2: DP2; TestPoint_Pad_1.0x1.0mm
DP3: DP3; TestPoint_Pad_1.0x1.0mm
J1: Conn_02x14_Odd_Even; PinHeader_2x14_P2.54mm_Vertical
JP1_2, JP2_1, JP5_3, JP6_2, JP7_1, JP9_3: Jumper_2_Open; SolderJumper-2_P1.3mm_Open_RoundedPad1.0x1.5mm
JPGND1, JPGND2, JPGND3: Jumper_2_Open; SolderJumper-2_P1.3mm_Open_RoundedPad1.0x1.5mm
LED1, LED2, LED3: IR333C; LED_D3.0mm_Horizontal_O1.27mm_Z2.0mm_Clear; Mouser Part Number 638-IR333C
Q1, Q2, Q3: MMBF170; SOT-23
Q1_teft43_1, Q5_teft43_2, Q6_teft43_3: TEFT4300; LED_D3.0mm_Horizontal_O1.27mm_Z2.0mm_IRBlack; Mouser Part Number 782-TEFT4300
QP1: QP1; TestPoint_Pad_1.0x1.0mm
QP2: QP2; TestPoint_Pad_1.0x1.0mm
QP3: QP3; TestPoint_Pad_D1.0mm
R1, R2, R5: 100; R_0805_2012Metric_Pad1.20x1.40mm_HandSolder
R3, R4, R6: 47k; R_0805_2012Metric
R7, R8, R9: 47; R_0805_2012Metric_Pad1.20x1.40mm_HandSolder
R10, R12, R16: 470; R_0805_2012Metric_Pad1.20x1.40mm_HandSolder
R11, R13, R17: 1.5k; R_0805_2012Metric_Pad1.20x1.40mm_HandSolder
R18, R19, R21: 18k; R_0805_2012Metric_Pad1.20x1.40mm_HandSolder
SOP1: SOP1; TestPoint_Pad_1.0x1.0mm
SOP2: SOP2; TestPoint_Pad_1.0x1.0mm
SOP3: SOP3; TestPoint_Pad_1.0x1.0mm
TPGND1: TestPoint; TestPoint_Pad_1.0x1.0mm
TPbatt1: TestPoint; TestPoint_Pad_D1.0mm
U1: LM324; SOIC-14_3.9x8.7mm_P1.27mm
VO1: VO1; TestPoint_Pad_D1.5mm
VO2: VO2; TestPoint_Pad_D1.0mm
VO3: VO3; TestPoint_Pad_D1.5mm
mosP1: MosP1; TestPoint_Pad_1.0x1.0mm
mosP2: MosP2; TestPoint_Pad_1.0x1.0mm
mosP3: MosP3; TestPoint_Pad_1.0x1.0mm

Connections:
/AB0: J1.25
/PA3: J1.5, SOP1.1, U1.1, U1.2 (-)
/PA4: J1.7
/PA5: J1.11
/PA6: J1.13, SOP2.1, U1.6 (-), U1.7
/PA7: J1.17, SOP3.1, U1.8, U1.9 (-)
/PC4: J1.19
/PC5: J1.23
/PE8(PWM): J1.22, R1.2
/PE9(PWM): J1.20
/PE10(PWM): J1.18
/PE11(PWM): J1.16
/PE12(PWM): J1.14
/PE13(PWM): J1.12, R2.2
/PE14(PWM): J1.10
/PE15(PWM): J1.8, R5.2
/V1_out: JP2_1.1 (A), JP7_1.1 (A), R12.1, U1.10 (+), VO1.1
/V2_out: JP1_2.1 (A), JP6_2.1 (A), R10.1, U1.3 (+), VO2.1
/V3_out: JP5_3.1 (A), JP9_3.1 (A), R16.1, U1.5 (+), VO3.1
GND: C1.2, C2.2, C3.2, J1.3, J1.9, J1.15, J1.21, J1.27, JPGND1.2 (B), JPGND2.2 (B), JPGND3.2 (B), Q1.2 (S), Q2.2 (S), Q3.2 (S), R3.1, R4.1, R6.1, R11.1, R13.1, R17.1, R18.1, R19.1, R21.1, TPGND1.1, U1.11 (V-), U1.12 (+), U1.13 (-)
unnamed: DP2.1, JPGND2.1 (A), LED2.2, Q1.3 (D)
unnamed: DP3.1, JPGND3.1 (A), LED3.2, Q3.3 (D)
unnamed: JP1_2.2 (B), R11.2
unnamed: JP2_1.2 (B), R13.2
unnamed: JP5_3.2 (B), R17.2
unnamed: JP6_2.2 (B), R18.2
unnamed: JP7_1.2 (B), R19.2
unnamed: JP9_3.2 (B), R21.2
unnamed: LED1.1, R8.1
unnamed: DP1.1, JPGND1.1 (A), LED1.2, Q2.3 (D)
unnamed: LED2.1, R7.1
unnamed: LED3.1, R9.1
unnamed: Q1_teft43_1.1 (E), QP1.1, R12.2
unnamed: Q5_teft43_2.1 (E), QP2.1, R10.2
unnamed: Q6_teft43_3.1 (E), QP3.1, R16.2
unnamed: Q1.1 (G), R1.1, R3.2, mosP2.1
unnamed: Q2.1 (G), R2.1, R4.2, mosP1.1
unnamed: Q3.1 (G), R5.1, R6.2, mosP3.1
VCC: C1.1, C2.1, C3.1, J1.4, J1.26, Q1_teft43_1.2 (C), Q5_teft43_2.2 (C), Q6_teft43_3.2 (C), R7.2, R8.2, R9.2, TPbatt1.1, U1.4 (V+)

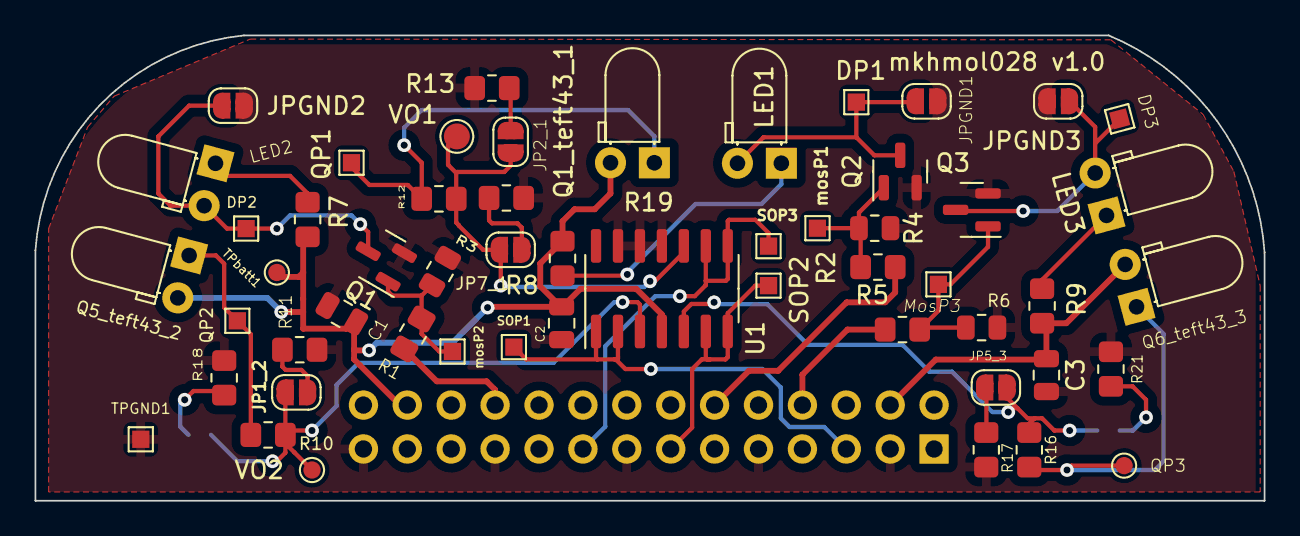
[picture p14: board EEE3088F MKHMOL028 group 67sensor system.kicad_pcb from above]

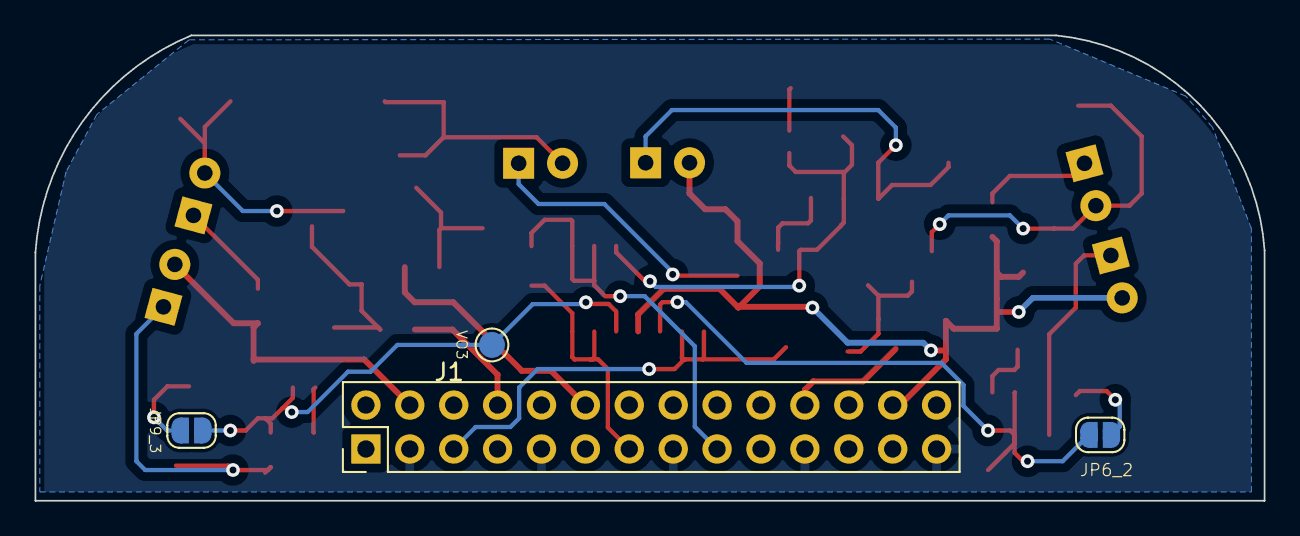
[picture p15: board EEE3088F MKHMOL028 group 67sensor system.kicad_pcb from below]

Board: 2 copper layers, 71.1 x 26.9 mm, 58 parts (4 on the bottom side), 29 nets.

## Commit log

2024-04-20 Add files via upload
    first commit of the PCB design
    [EEE3088F MKHMOL028 group 67sensor system.kicad_pcb, EEE3088F MKHMOL028 group 67sensor system.kicad_sch]
2025-08-21 Molise _sensor board documentation
